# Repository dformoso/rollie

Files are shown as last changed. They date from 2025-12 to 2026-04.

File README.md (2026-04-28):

# Rollie

 

A gravity-stabilised spherical robot — a camera on wheels, where the "wheels" are a hollow 120mm ball and the camera floats at the centre of gravity. It rolls by shifting its own internal mass: pitch the internal weighted platform forward and the ball follows.

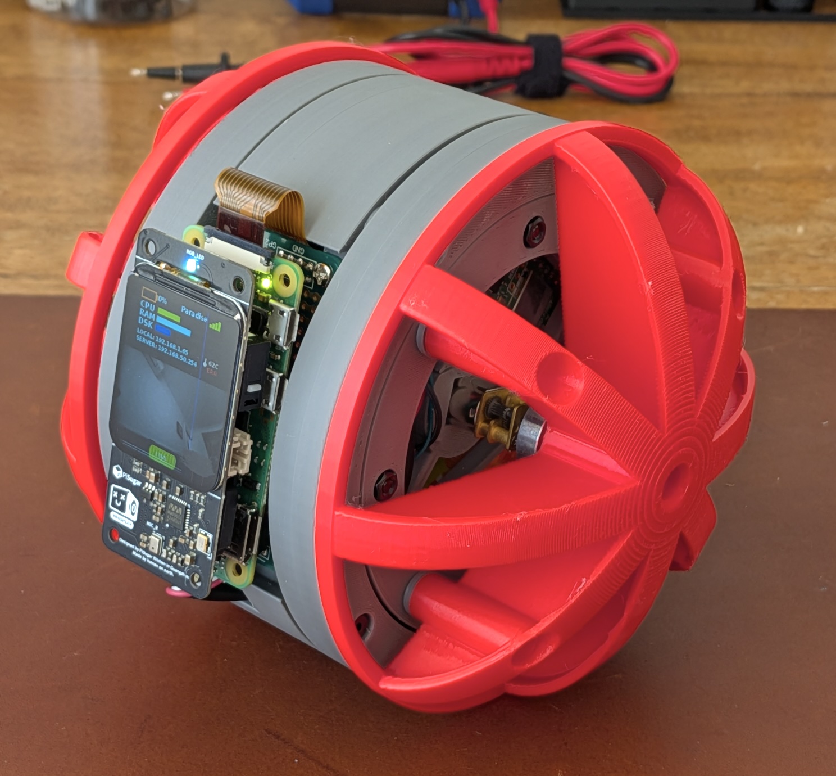
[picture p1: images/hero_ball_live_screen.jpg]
Assembled Rollie — red 3D-printed shells closed around the internal stator, WhisPlay screen showing the live camera feed
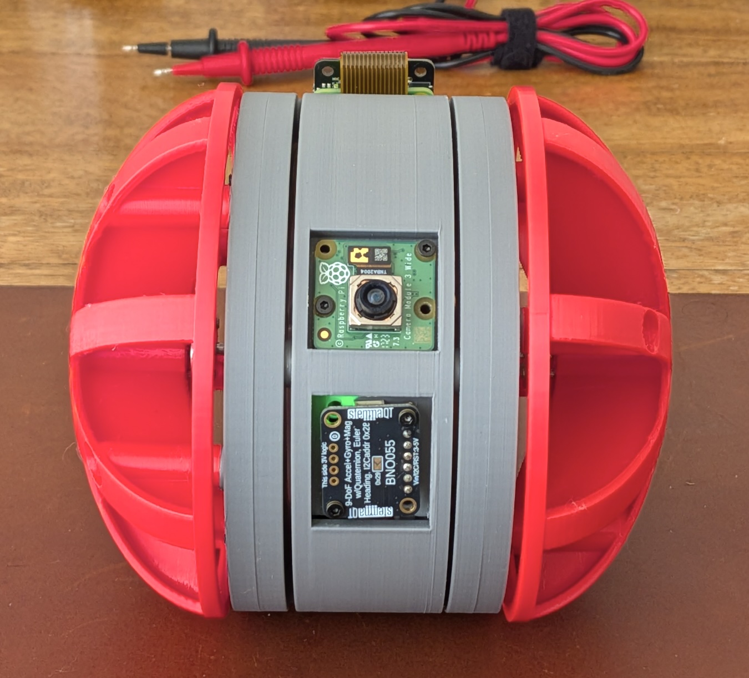
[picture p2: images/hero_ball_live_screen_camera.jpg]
Front view through the equatorial gap — Camera Module 3 Wide and BNO055 IMU exposed between the two red shell halves
&nbsp;&nbsp;

---

## Motivation

This project began with a simple wish: to have more photos and videos together with my son.

I came across [Samsung's concept robot Ballie](https://www.youtube.com/watch?v=v0XdLGYaNMw) — a cheerful, rolling ball that follows you around — and thought: *what if I built one myself?* A little companion that could chase us around the house and capture the everyday moments that are so easy to miss.

The project felt like the right kind of ambitious. Complex enough to keep me engaged for years, but tangible enough to make real progress in the hour I carve out each evening after he goes to sleep.

---

## The Experiment: AI as Co-Engineer

This project started as a question: *how far can AI assistance extend beyond software development?*

The code is the least interesting part. Every engineering layer was designed in collaboration with AI models:

- **Mechanical design** — the slewing bearing rings, stator frame, cradle, and motor hubs were designed iteratively in OpenSCAD with AI help: from geometry constraints and print tolerance adjustments to resolving mechanical interference across 13+ versions of each part.

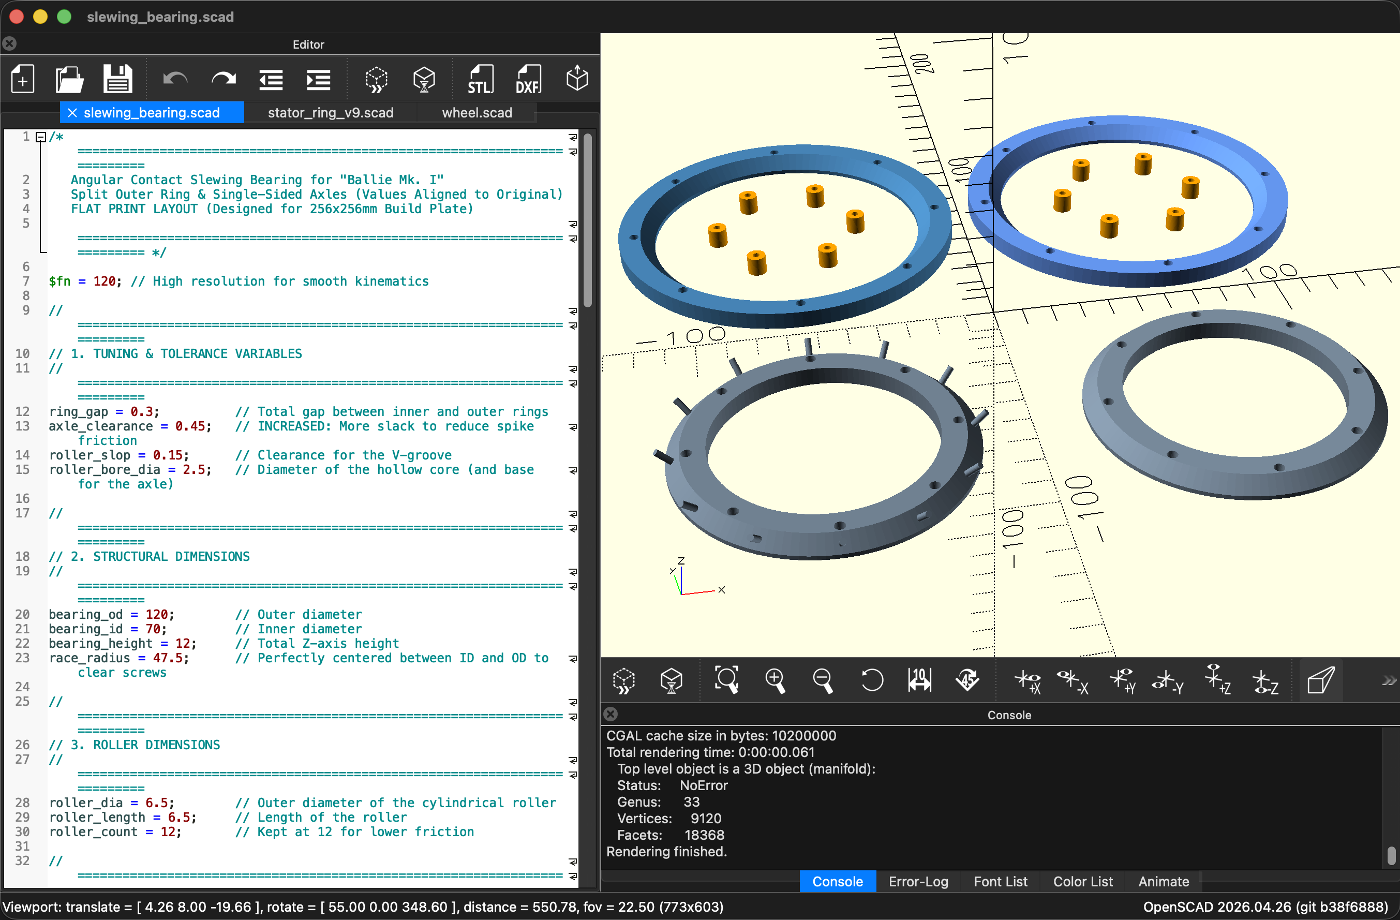
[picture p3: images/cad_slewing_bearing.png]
OpenSCAD source on the left, rendered slewing bearing rings on the right
  

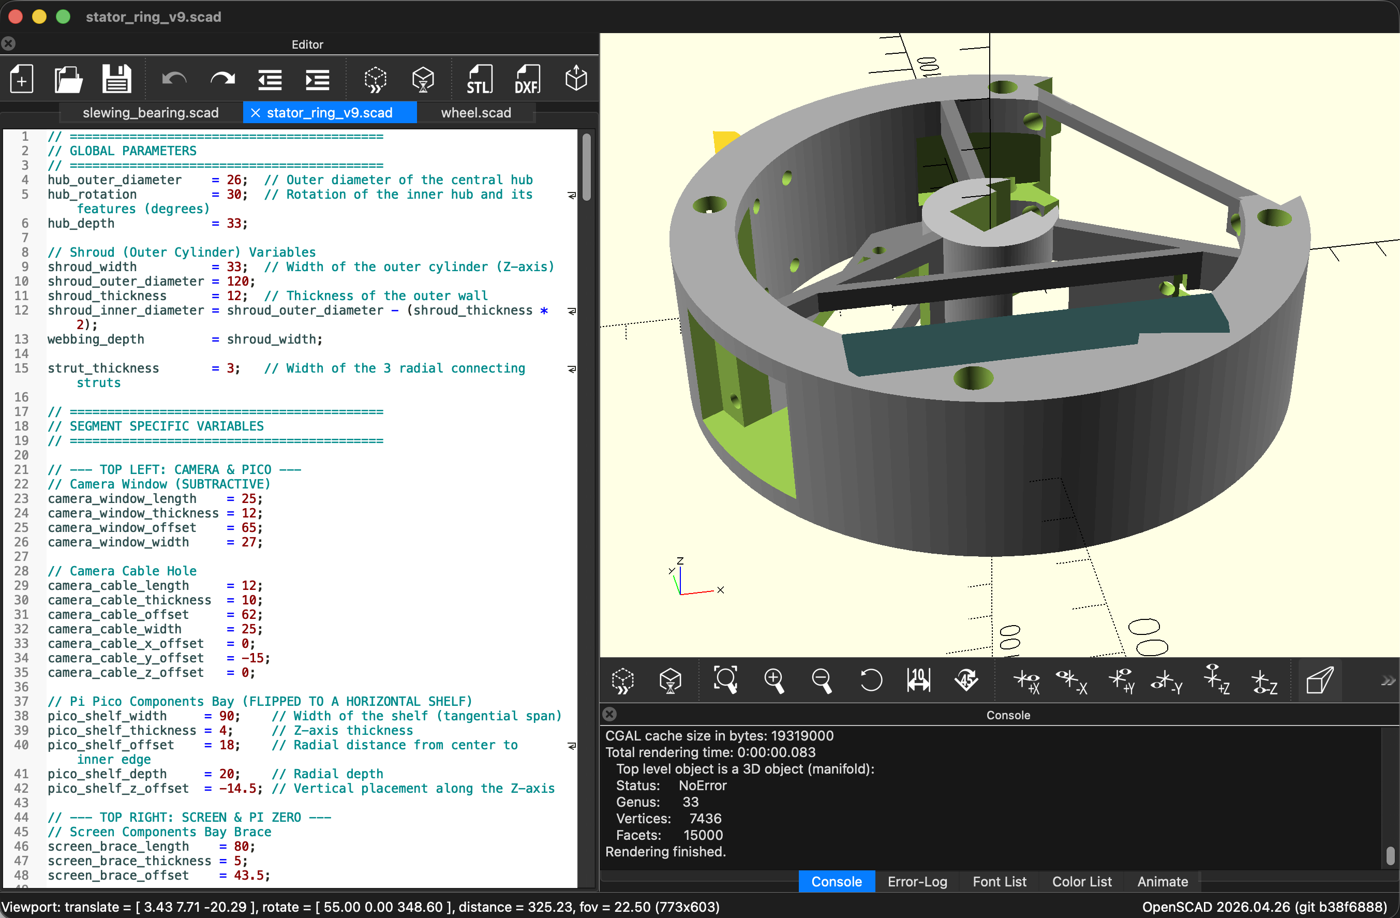
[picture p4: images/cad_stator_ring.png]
OpenSCAD source on the left, rendered stator ring on the right
  

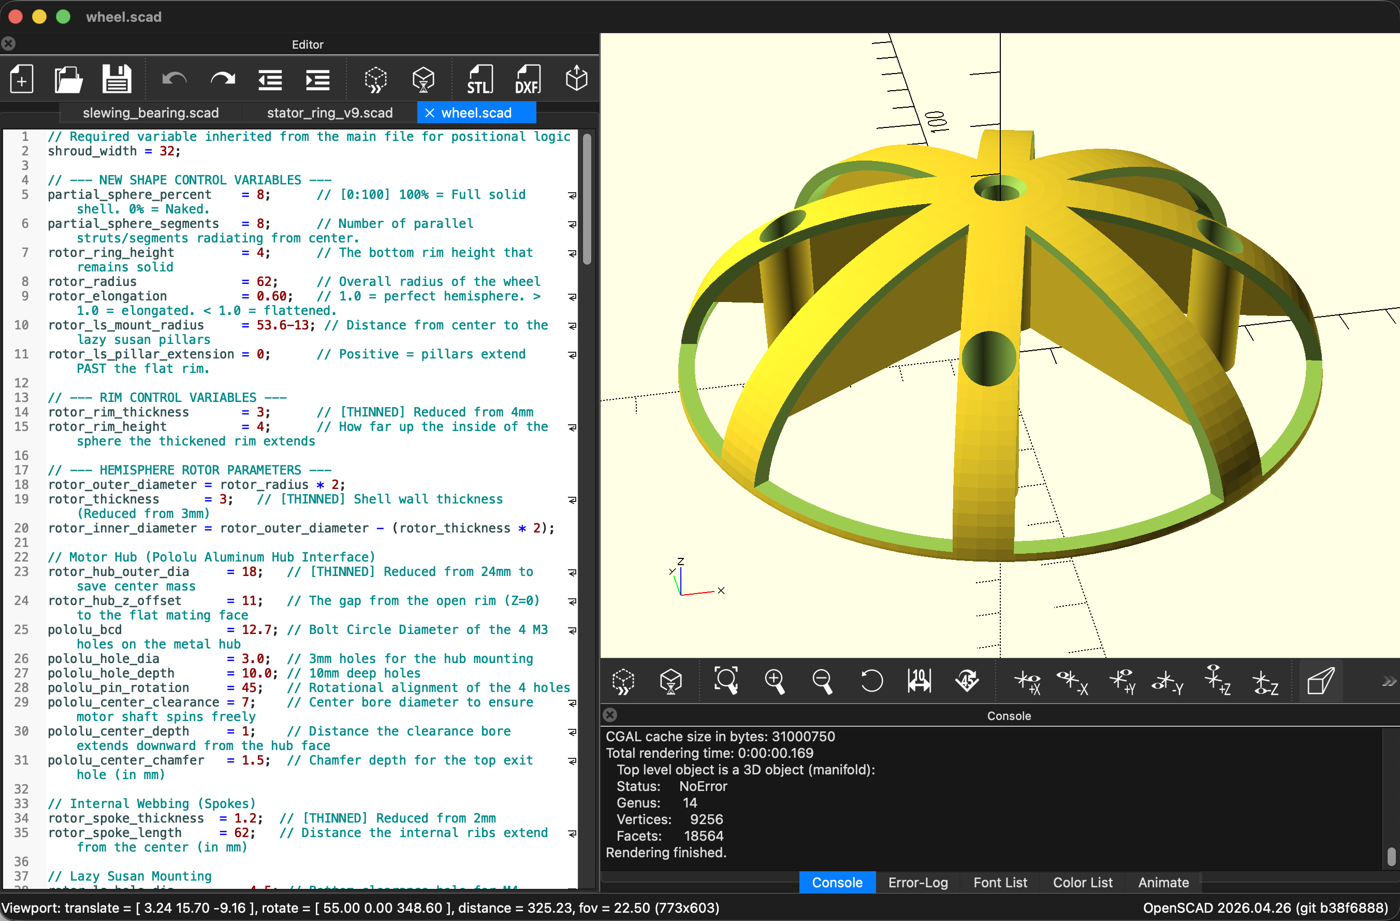
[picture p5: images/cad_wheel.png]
OpenSCAD source on the left, rendered motor wheel hub on the right
  

- **Bill of materials** — the parts list itself (motors, regulator, IMU, bearings, battery, displays) was researched and assembled with AI assistance.

- **Electronic engineering** — wiring layout, component selection, pin assignment (including resolving conflicts between the Motor SHIM's DRV8833, I2C bus, and UART0), and power budgeting were all mapped with AI assistance from a YAML connection list rendered into a wiring diagram.

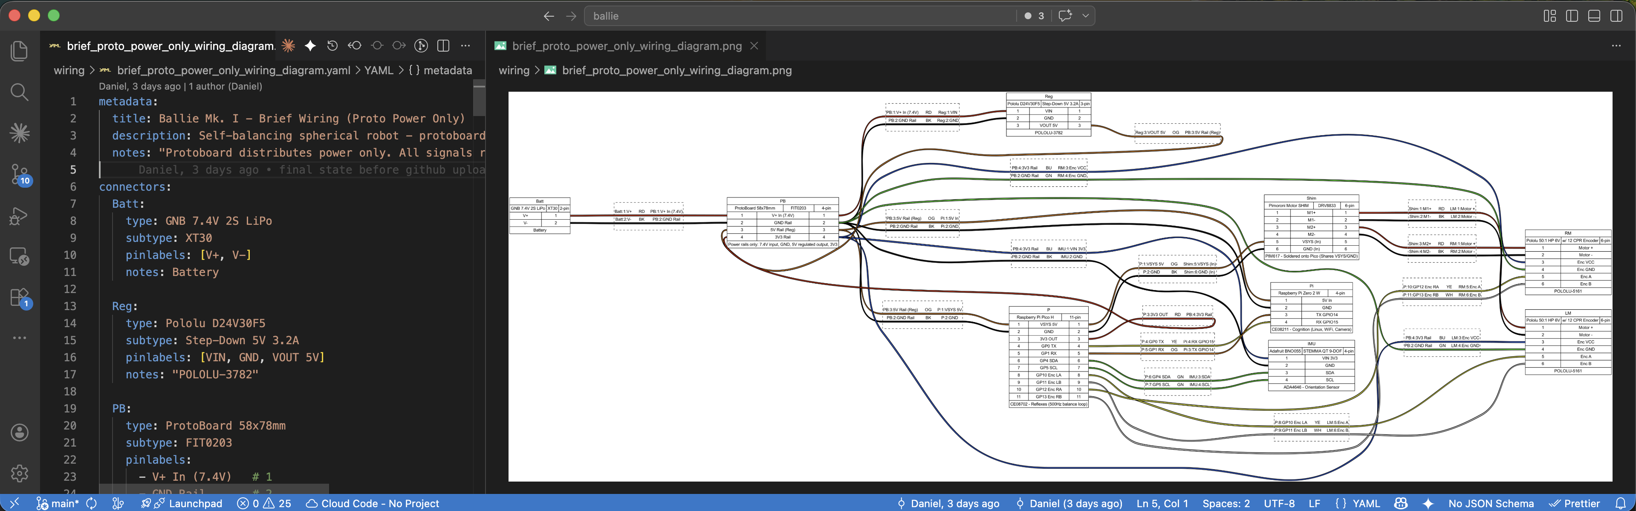
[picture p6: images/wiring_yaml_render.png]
Wiring YAML source open in an editor next to its rendered wiring diagram
  

- **Embedded control** — the split-brain architecture, PID angle controller structure, and motor deadband calibration were designed and reasoned through with AI.

The robot is a physical artefact of that process. It exists to answer the question concretely.

**What AI is not doing (yet):** the models are not steering the robot. Autonomous navigation and perception are a future goal, likely with a small onboard model (Gemma-class). For now, Rollie is remote-controlled.

---

## How It Works

### The Drive Mechanism

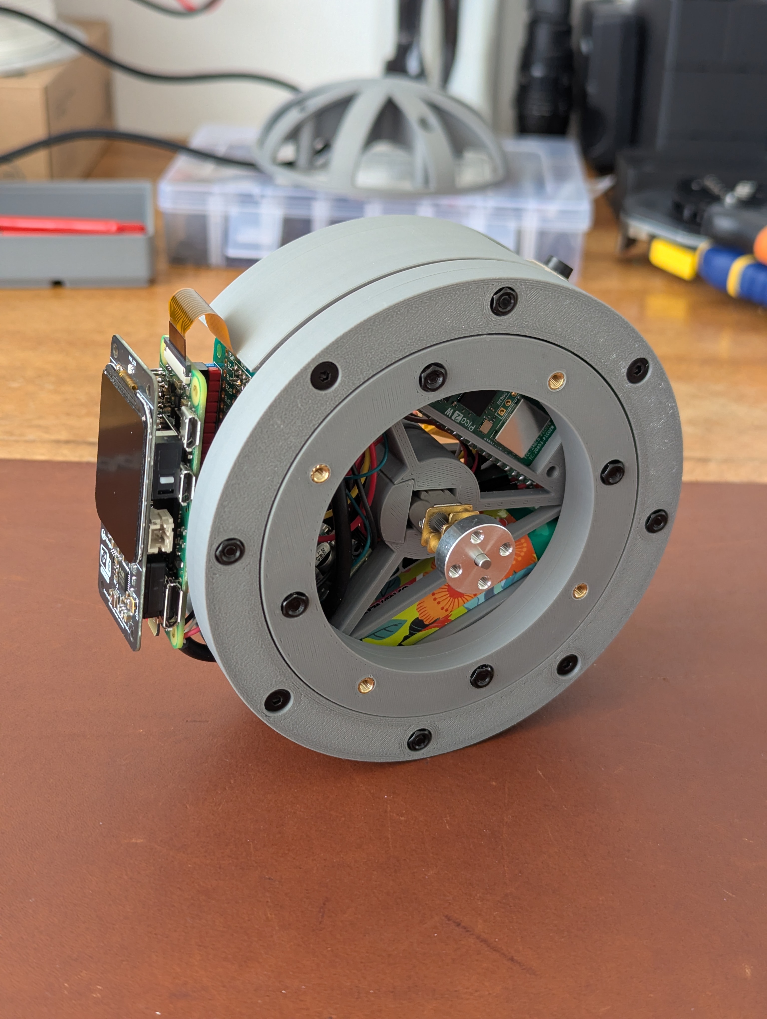
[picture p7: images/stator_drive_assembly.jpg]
Stator drive assembly — both 75mm slewing bearings mounted, motor hub centred, electronics nested inside, before the outer shells go on


Inside the ball is a weighted internal platform — the *stator* — that hangs like a pendulum. Gravity pulls its battery-laden base downward, keeping it vertical. Two motors mounted on the stator drive the outer shell (the *rotor*) through 75mm slewing bearings. Because the stator resists rotation (gravity), the motor reaction force rolls the shell.

To roll forward: command the stator to pitch forward. The centre of mass shifts. The ball follows.

### Architecture: The Split Brain

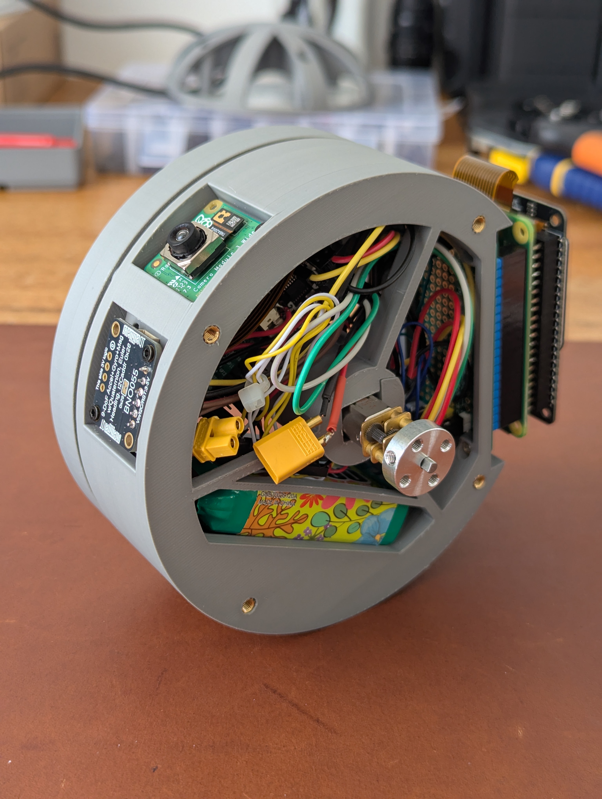
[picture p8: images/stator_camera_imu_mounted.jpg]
Stator with the BNO055 IMU and Camera Module 3 mounted on the top shelf, with the Pi Zero stack visible inside


| Layer | Hardware | Role |
|---|---|---|
| Reflexes | Raspberry Pi Pico 2 W | 100 Hz PID angle control, IMU reading, raw motor PWM |
| Cognition | Raspberry Pi Zero 2 W | Camera streaming, high-level commands, future AI |
| Sensor | Adafruit BNO055 IMU | Absolute orientation via fused Euler angles |
| Driver | Pimoroni Motor SHIM | DRV8833 dual H-bridge for two gear motors |
| Display | WhisPlay (PiSugar 3 HAT) | Live camera feed + system HUD on a 240×280 LCD |

The Pico acts as an *angle-holding coprocessor*. It receives target pitch and yaw angles over UART and runs a PID loop to hold the stator at that angle — which causes the ball to move at the corresponding speed. The Pi Zero (or a dev machine via USB) sends commands:

```
<PITCH:12>   → hold stator at 12° forward tilt (ball rolls forward)
<YAW:5>      → apply differential steering offset
<STOP>       → emergency stop, target = 0°
```

---

## Hardware

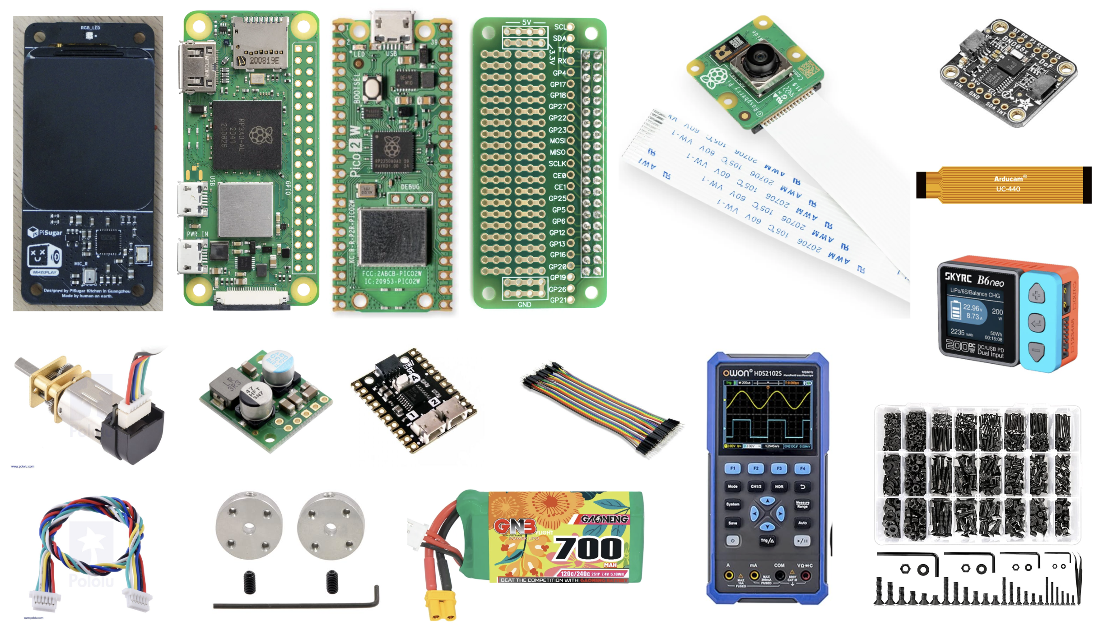
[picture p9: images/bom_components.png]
Component lineup — Pi Zero 2 W, Pico 2 W, Motor SHIM, Camera Module 3, BNO055 IMU, micro metal gearmotors, 5V regulator, 2S LiPo, jumpers, and the test gear that lived next to the bench


Full parts list, pin maps, and wiring tables: [docs/overview.md](docs/overview.md)

**Core components:**

| Qty | Component |
|---|---|
| 1 | Raspberry Pi Zero 2 W |
| 1 | Raspberry Pi Pico 2 W |
| 1 | Adafruit BNO055 9-DOF IMU (STEMMA QT) |
| 1 | Pimoroni Motor SHIM for Pico |
| 2 | Pololu 50:1 Micro Metal Gearmotor HP 6V (extended shaft + encoder) |
| 1 | Pololu 5V 3.2A Step-Down Regulator (D24V30F5) |
| 2 | 75mm Slewing Bearings |
| 1 | GNB 7.4V 2S LiPo (XT30) |
| 1 | PiSugar 3 Battery HAT |
| 1 | Raspberry Pi Camera Module 3 Wide |

---

## Build Guide

### 3D Printing

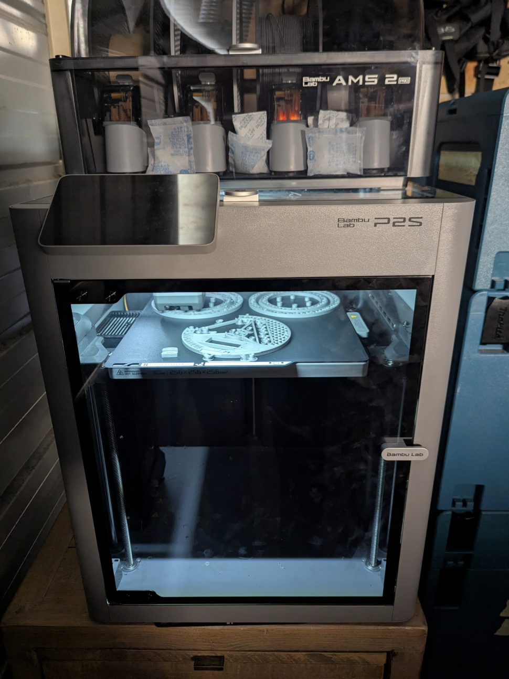
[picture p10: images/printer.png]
Bambu P2S printer with AMS, mid-print on a tray of stator parts


Print the following final STLs from [`cad/`](cad/):

| File | Part | Notes |
|---|---|---|
| `stator_ring_v13.stl` | Internal weighted cylinder | Main structural part |
| `wheel_v13.stl` | Motor wheel hubs | Print ×2 |
| `slewing_bearing_v6_half_plate.stl` | Slewing bearing ring (rigid) | Print ×2 per bearing |
| `slewing_bearing_flexible.stl` | Slewing bearing ring (TPU) | Alternative for grip |
| `cradle_v2.stl` | Electronics mounting cradle | Holds Pi + battery |

SCAD source files for all parts are in `cad/`. Intermediate design iterations are preserved in [`cad/archive/`](cad/archive/).

### Assembly and Wiring
See [docs/overview.md](docs/overview.md) for:

- Full GPIO pin map (Motor SHIM, BNO055, UART, encoders)
- Step-by-step wiring tables with wire colours
- Assembly notes (SHIM sandwich, keel weight placement, cable routing)

---

## Software Setup

### Pico Firmware (MicroPython)

The Pico runs [Pimoroni MicroPython](https://github.com/pimoroni/pimoroni-pico) (v1.27.0+). Flash the UF2 via `sync_and_run_on_py.sh` (see below) or manually.

Deploy firmware files to the Pico:

```bash
python3 pico-shim-firmware/deploy_to_pico.py pico-shim-firmware/
```

The three firmware files are:
- `pico-shim-firmware/main.py` — PID angle controller (main loop)
- `pico-shim-firmware/boot.py` — UART init and boot banner
- `pico-shim-firmware/bno055_minimal.py` — BNO055 I2C driver stub (see note below)

> **BNO055 note:** In v0.1 the IMU driver is a stub. The Pico runs in *Direct Drive* mode, where `<PITCH:x>` maps directly to motor speed rather than a closed-loop angle. A full I2C driver is the next integration step.

### Pi Zero Setup

```bash
cd rollie/
cp config.py.example config.py       # fill in your values
bash install_dependencies.sh
```

---

## Usage

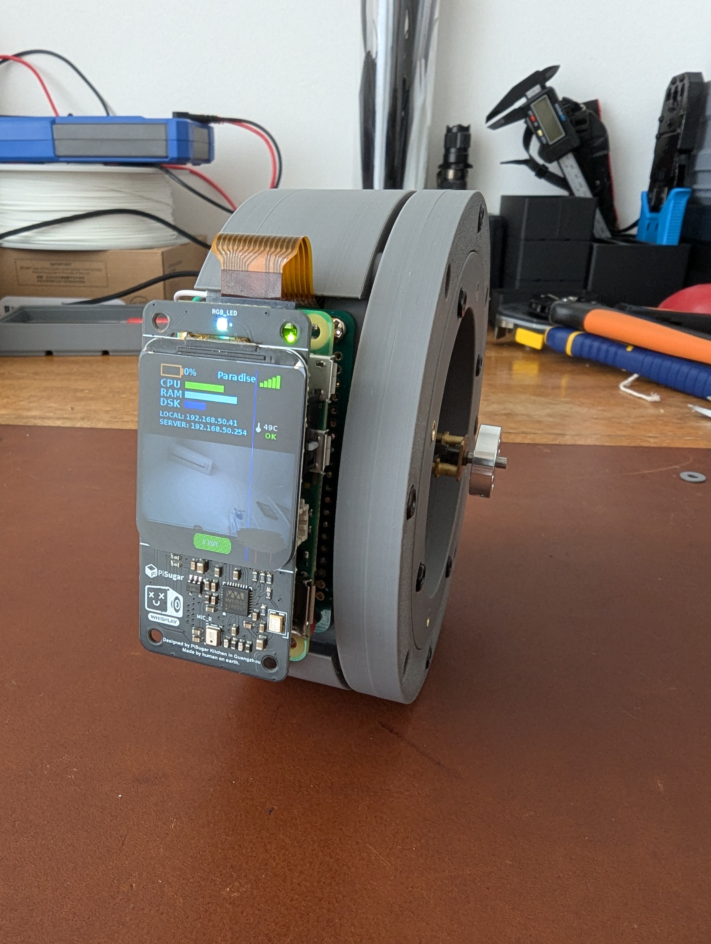
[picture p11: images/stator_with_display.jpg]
WhisPlay display showing the system HUD — CPU, RAM, disk, WiFi, IP addresses, and CPU temperature — on the side of the partially-built stator


### Keyboard Control (dev machine via USB)

Connect the Pico via USB, then:

```bash
python3 pico-shim-firmware/keyboard_control.py
```

| Key | Action |
|---|---|
| W / ↑ | Pitch forward (roll forward) |
| S / ↓ | Pitch backward |
| A / ← | Yaw left |
| D / → | Yaw right |
| Space | Stop |
| +/- | Adjust pitch step size |
| R | Request status |
| Q | Quit |

### Full Deploy to Pi Zero

```bash
cd rollie/
cp sync_config.sh.example sync_config.sh   # fill in Pi IP and credentials
bash sync_and_run_on_py.sh                 # sync + run in foreground
bash sync_and_run_on_py.sh background on   # install as a systemd service
```

---

## Current State — v0.1

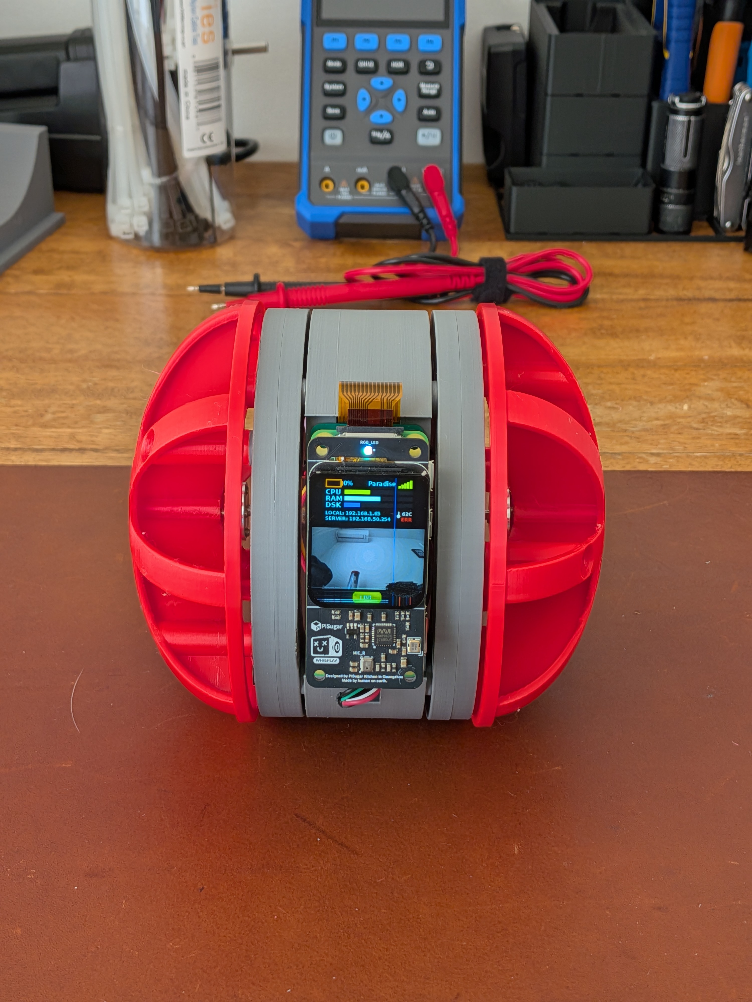
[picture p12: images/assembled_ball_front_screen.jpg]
Assembled Rollie, front-on, screen showing the live camera feed through the equatorial gap
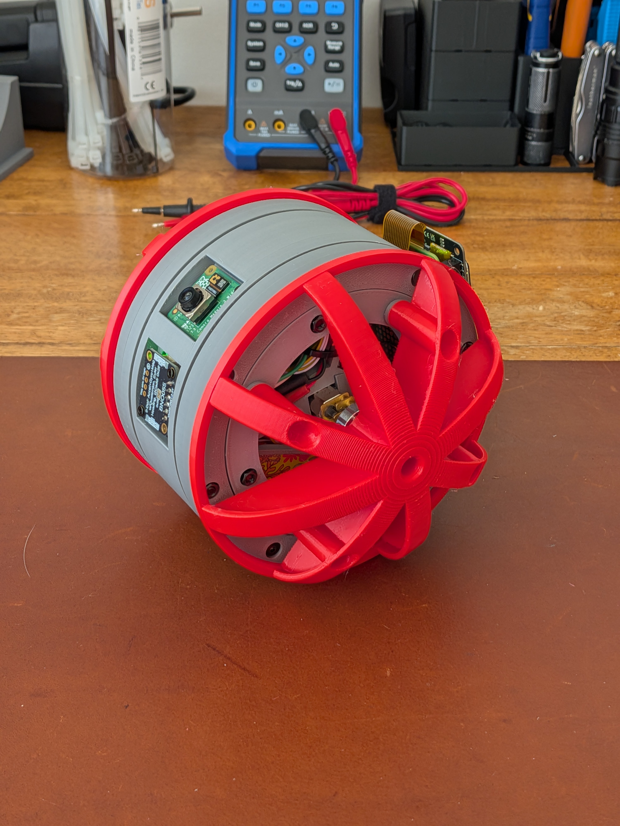
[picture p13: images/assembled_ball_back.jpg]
Assembled Rollie, side/back view, shells closed
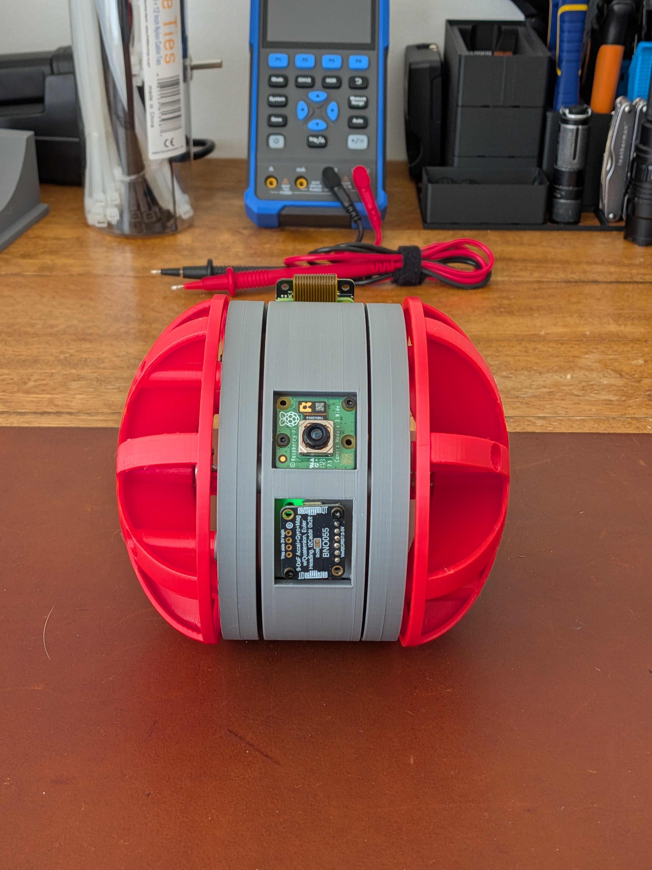
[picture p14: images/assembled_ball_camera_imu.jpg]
Front view through the equatorial gap — Camera Module 3 and BNO055 IMU exposed between the two red shell halves
&nbsp;&nbsp;&nbsp;&nbsp;

A short clip of it rolling: [`images/ball_rolling.mp4`](images/ball_rolling.mp4).

**Working:**
- Physical drive mechanism — ball rolls from pendulum mass shift
- Motor PID velocity loop with encoder feedback
- Camera feed with live system HUD (battery, CPU, WiFi, temperature) on WhisPlay display
- Short-press button: start/stop video + audio recording (auto-muxed to MP4)
- Long-press button: toggle demo mode (sends `<PITCH:30>` to Pico)
- Keyboard control from dev machine (USB) or Pi Zero (UART)

**Not yet integrated:**
- BNO055 IMU closed-loop angle control (currently Direct Drive — stator angle is not sensed)
- End-to-end Pi Zero → Pico UART path (wired, integration untested)
- Onboard AI inference

---

## Next Iteration

The v0.2 goal is to rebuild the control loop in simulation, removing the hardware barrier entirely:

- **Microcontroller sim** — replace the physical Pico with a simulated ESP32 running in [Wokwi](https://wokwi.com/)
- **Physics sim** — a pendulum-in-sphere model (PyBullet or a lightweight 2D pendulum sim) to replace the physical ball
- **Environment sim** — simulated terrain and synthetic camera input
- **AI inference** — a Gemma-class model receiving camera frames and issuing `<PITCH>` / `<YAW>` commands

This makes the project forkable and runnable without hardware, enables RL-based PID tuning, and is a prerequisite for training end-to-end navigation policies.

---

## License

[MIT](LICENSE) — Daniel Martinez Formoso, 2025

---

*Written with Gemini and Claude.*

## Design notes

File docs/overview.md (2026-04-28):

# Project Description: The "Rollie Mk. I" — Spherical Robot

## 1. Overview

**Objective**
To construct an autonomous spherical robot (approx. 120mm diameter) using a gravity-stabilized internal pendulum ("hamster") drive. The robot rolls by displacing its internal center of mass — pitching the stator forward causes the ball to roll forward.

### Core Architecture (The "Split-Brain")

* **The Reflexes (Cerebellum):** A **Raspberry Pi Pico 2 W** runs a dedicated MicroPython control loop. It reads the **BNO055 IMU** and drives the motors via the **Pimoroni Motor SHIM** to hold a precise pitch angle. It acts as an **Angle-Holding Coprocessor**.
* **The Cognition (Cerebrum):** A **Raspberry Pi Zero 2 W** runs Linux. It handles WiFi, Computer Vision (Pi Camera), AI, and high-level path planning. It sends angle commands (e.g., `<PITCH:12>`) to the Pico via UART.

### The Drive Mechanism (Gravity-Stabilized Pendulum)

1. **Stator (Internal):** A weighted cylinder hangs inside the ball. Gravity pulls its battery-laden bottom (**Keel**) downwards, keeping it vertical.
2. **Rotor (External):** Two hemispherical shells form the "skin," mechanically isolated from the Stator by Lazy Susan bearings.
3. **Action:** Motors bolted to the Stator drive the Rotors. Since the Stator resists rotation (gravity), the force rolls the ball. To roll forward, the Pico pitches the stator forward, shifting the center of mass.

---

## 2. Pico Firmware Architecture (The 5-Step Tethered Checklist)

### Step 1: Sensor Fusion (Zeroing the Pendulum)

The BNO055 IMU provides fused accelerometer + gyroscope data. Inside a rolling sphere, the stator acts like a pendulum susceptible to harmonic swinging (wobbling when stopping).

**Goal:** Fast, clean reading of the stator's absolute pitch relative to gravity. Software filter tuned to ignore high-frequency wheel vibrations while catching low-frequency pendulum swings so the motors can counteract them.

The BNO055 runs its own Cortex-M0 sensor fusion internally — we read Euler angles directly via I2C.

### Step 2: PID "Angle Tracking" Loop

Unlike a standard balancing robot (target = 0°), in Rollie the **target angle dictates speed**.

- **Target 0°** → stationary (camera level)
- **Target 10°** → rolling forward at constant speed
- **Target -10°** → rolling backward

The PID loop must smoothly drive motors to hit the target and lock it there rigidly, preventing the stator from bouncing (e.g., between 5° and 15° when targeting 10°).

### Step 3: Motor Deadband & Shell Traction

Find the exact minimum motor power to overcome rolling resistance of the shell on the floor. If the PID commands a small angle change but motors can't overcome friction, the integral term winds up and eventually jerks the camera violently. Deadband calibration ensures smooth, cinematic panning.

### Step 4: Anti-Tumble Limit

If acceleration is too aggressive or the ball hits an obstacle, the stator can swing 360° inside the shell, tearing wiring. **Hard angle limit:** if pitch exceeds ±45°, the Pico instantly overrides PID and applies reverse torque / dynamic braking.

### Step 5: UART Listener (Pi Zero → Pico)

The Pi Zero sends commands like `<PITCH:12>` via UART. The Pico receives the target, executes the PID loop to hold the stator at exactly 12°, and the ball rolls as a physical result.

**Protocol:**
- `<PITCH:xx>` — set target pitch angle (positive = forward)
- `<YAW:xx>` — differential steering (positive = right)
- `<STOP>` — emergency stop, target = 0°, braking

---

## 3. Hardware Pin Map

### Pimoroni Motor SHIM (Soldered onto Pico)

The SHIM is soldered directly onto the top of the Pico headers as per manual. It uses a DRV8833 dual H-bridge.

| Function | GPIO | Physical Pin | Notes |
|---|---|---|---|
| Motor A IN1 | GP6 | Pin 9 | SHIM internal (do NOT use) |
| Motor A IN2 | GP7 | Pin 10 | SHIM internal (do NOT use) |
| Motor B IN1 | GP27 | Pin 32 | SHIM internal (do NOT use) |
| Motor B IN2 | GP26 | Pin 31 | SHIM internal (do NOT use) |
| I2C SDA (STEMMA QT) | GP4 | Pin 6 | (Unused, moved to GP2 to free up UART0) |
| I2C SCL (STEMMA QT) | GP5 | Pin 7 | (Unused, moved to GP3 to free up UART0) |
| NSLEEP | 3V3_EN | — | Always enabled |

### BNO055 IMU (Moved from SHIM STEMMA QT Connector)

The STEMMA QT cable data lines must be routed to GP2 (SDA) and GP3 (SCL) instead of the SHIM's directly.

| BNO055 Pin | Pico Pin | Function |
|---|---|---|
| VIN | 3V3 | Power |
| GND | GND | Ground |
| SDA | GP2 | I2C Data (Moved from GP4) |
| SCL | GP3 | I2C Clock (Moved from GP5) |

I2C Address: `0x28` (default)

### UART — Brain Link (Pi Zero ↔ Pico)

Wires crossed (TX→RX):

| Pi Zero 2 W | Pin # | Pico | Pin # | Wire Color |
|---|---|---|---|---|
| GPIO 14 (TX) | Pin 8 | GP 1 (RX) | Pin 2 | Yellow |
| GPIO 15 (RX) | Pin 10 | GP 0 (TX) | Pin 1 | Orange |
| GND | Pin 6 | GND | Pin 3 | **Black** |

### Motor Encoders (Pololu 50:1 HP with 12 CPR)

**Motor power wires** (Red + Black) connect to the SHIM's motor output pads (soldered).
**Encoder signal wires** connect to Pico GPIO pins (via Dupont connectors to headers).

**Left Motor (Motor 1 / SHIM Motor A)**

| Signal | Wire Color | Connects To | Pin |
|---|---|---|---|
| Motor (+) | Red (thick) | SHIM Pad 1+ | Soldered |
| Motor (−) | Black (thick) | SHIM Pad 1− | Soldered |
| Encoder VCC | Blue | Pico 3V3(OUT) | Pin 36 |
| Encoder GND | Green | Common GND rail | Protoboard |
| Encoder Ch A | Yellow | Pico **GP18** | Pin 24 |
| Encoder Ch B | White | Pico **GP19** | Pin 25 |

**Right Motor (Motor 2 / SHIM Motor B)**

| Signal | Wire Color | Connects To | Pin |
|---|---|---|---|
| Motor (+) | Red (thick) | SHIM Pad 2+ | Soldered |
| Motor (−) | Black (thick) | SHIM Pad 2− | Soldered |
| Encoder VCC | Blue | Pico 3V3(OUT) | Pin 36 |
| Encoder GND | Green | Common GND rail | Protoboard |
| Encoder Ch A | Yellow | Pico **GP16** | Pin 21 |
| Encoder Ch B | White | Pico **GP17** | Pin 22 |

> **Encoder Pin Warning:** Do NOT move encoders to GP6, 7, 26, or 27. Those are used by the Motor SHIM's DRV8833.

### Encoder Constants

| Parameter | Value |
|---|---|
| Motor gear ratio | 51.45:1 |
| Encoder CPR (motor shaft) | 12 |
| Counts per output revolution | 12 × 51.45 ≈ **617** |

---

## 4. Full Parts Listing

### Electronics Core

| Qty | Component | Product Name | SKU |
|---|---|---|---|
| 1 | Brain | Raspberry Pi Zero 2 W | CE08211 |
| 1 | Reflexes | Raspberry Pi Pico 2 W | — |
| 1 | IMU | Adafruit BNO055 9-DOF (STEMMA QT) | ADA4646 |
| 1 | Regulator | Pololu 5V, 3.2A Step-Down (D24V30F5) | POLOLU-3782 |
| 1 | Motor Driver | Pimoroni Motor SHIM for Pico | PIM617 |
| 1 | Motherboard | ProtoBoard 2" (58×78mm) | FIT0203 |

### Drive System

| Qty | Component | Product Name | SKU |
|---|---|---|---|
| 2 | Motors | Pololu 50:1 Micro Metal Gearmotor HP 6V (Extended Shaft + Encoder) | POLOLU-5161 |
| 2 | Cables | 6-Pin JST SH-Style Cable (16cm) | POLOLU-4766 |
| 2 | Bearings | 75mm Lazy Susan Bearing | — |
| 1 | Battery | GNB 7.4V 2S LiPo (XT30) | — |

---

## 5. Assembly Notes

> **The SHIM Sandwich:** Solder the Pimoroni Motor SHIM onto the Pico's pins **before** plugging the Pico into the motherboard sockets. Text on SHIM and pin labels on Pico back should face each other.

> **BNO055 Connection:** The BNO055 SDA connects to Pico GP2 and SCL to GP3 (moved from the SHIM's default GP4/GP5 to avoid UART conflicts). Power and ground can still be drawn from the SHIM or common rails.

> **Cable Modifications:** The 6-pin Pololu motor cables were severed — thick Red+Black soldered to SHIM motor pads, thin Green/White/Yellow/Blue crimped with Dupont connectors for Pico GPIO headers.

> **The Keel Weight:** Battery must be mounted as low as possible inside the stator ring. The robot will not balance correctly if the battery is high.

> **Cable Slack:** Motor cables must be zip-tied to the Stator frame so they don't rub against the rotating Lazy Susan or outer shells.

---

## 6. Software Stack

| Layer | Runs On | Language | Responsibility |
|---|---|---|---|
| `main.py` | Pico 2 W | MicroPython v1.27.0 | PID angle control, IMU reading, raw PWM motor driving, UART listening |
| `boot.py` | Pico 2 W | MicroPython | UART init, boot banner |
| `bno055_minimal.py` | Pico 2 W | MicroPython | Minimal BNO055 I2C driver |
| `camera_feed.py` | Pi Zero 2 W | Python 3 | Camera streaming, AI, high-level control |
| `sync_and_run_on_py.sh` | Dev Machine | Bash | Deploys firmware to Pico (USB), syncs to Pi Zero |
| `keyboard_control.py` | Dev Machine | Python 3 | Debug tool — sends angle commands via USB serial |

### Communication Flow

```
Dev Machine (keyboard_control.py)
    ↓ USB Serial (/dev/ttyACM0, 9600 baud)
Pico 2 W (main.py — PID angle controller)
    ↕ I2C1 (GP2/GP3)       ↕ PWM (SHIM GP6/7/26/27)
BNO055 IMU                  Motors (via DRV8833)

Future (untethered):
Pi Zero 2 W (camera_feed.py)
    ↓ UART0 (GP0/GP1, 9600 baud)
Pico 2 W (main.py)
```

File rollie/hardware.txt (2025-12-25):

Main Device: Raspberry Pi Zero 2W
HAT1: PiSugar 3 Whisplay
HAT2: PiSugar 3 Battery
Camera: Raspberry Pi Camera Module 3 Wide

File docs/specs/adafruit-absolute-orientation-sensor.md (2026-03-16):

# Adafruit BNO055 Absolute Orientation Sensor

> **Source:** [Adafruit Learning Guide](https://learn.adafruit.com/adafruit-bno055-absolute-orientation-sensor)
> **Last Updated:** 2025-05-16

---

## Overview

If you've ever ordered and wired up a 9-DOF sensor, chances are you've also realized the challenge of turning the sensor data from an accelerometer, gyroscope and magnetometer into actual "3D space orientation"! Orientation is a hard problem to solve. The sensor fusion algorithms (the secret sauce that blends accelerometer, magnetometer and gyroscope data into stable three-axis orientation output) can be mind-numbingly difficult to get right and implement on low cost real time systems.

Bosch is the first company to get this right by taking a MEMS accelerometer, magnetometer and gyroscope and putting them on a single die with a high speed ARM Cortex-M0 based processor to digest all the sensor data, abstract the sensor fusion and real time requirements away, and spit out data you can use in quaternions, Euler angles or vectors.

> **Note:** The BNO055 I2C implementation violates the I2C protocol in some circumstances. This causes it not to work well with certain chip families. It does not work well with NXP i.MX RT1011, and it does not work well with I2C multiplexers. With ESP32 and ESP32-S3, CircuitPython 9.2.2 and later (which use ESP-IDF 5.3.2 and later) work better. Operation with SAMD51, RP2040, STM32F4, and nRF52840 is more reliable.

The board includes SparkFun qwiic compatible STEMMA QT connectors for the I2C bus so you don't even need to solder!

### Data Output

The BNO055 can output the following sensor data:

- **Absolute Orientation (Euler Vector, 100Hz)** — Three axis orientation data based on a 360° sphere
- **Absolute Orientation (Quaternion, 100Hz)** — Four point quaternion output for more accurate data manipulation
- **Angular Velocity Vector (100Hz)** — Three axis of 'rotation speed' in rad/s
- **Acceleration Vector (100Hz)** — Three axis of acceleration (gravity + linear motion) in m/s²
- **Magnetic Field Strength Vector (20Hz)** — Three axis of magnetic field sensing in micro Tesla (uT)
- **Linear Acceleration Vector (100Hz)** — Three axis of linear acceleration data (acceleration minus gravity) in m/s²
- **Gravity Vector (100Hz)** — Three axis of gravitational acceleration (minus any movement) in m/s²
- **Temperature (1Hz)** — Ambient temperature in degrees Celsius

### Related Resources

- [Datasheet](https://adafru.it/f0H)
- [Adafruit BNO055 Library (GitHub)](https://adafru.it/f0I)
- [Comparing the BNO085 vs BNO055 (Adafruit Forums)](https://adafru.it/19Cb)

---

## Pinouts

> **Note:** The pin order on the STEMMA QT version of the board is not the same as the original version. The pins are the same otherwise.

### Power Pins

| Pin | Description |
|-----|---|
| **VIN** | 3.3–5.0V power supply input |
| **3VO** | 3.3V output from the on-board linear voltage regulator, up to ~50mA |
| **GND** | Common/GND pin for power and logic |

### I2C Pins

| Pin | Description |
|-----|---|
| **SCL** | I2C clock pin. Works with 3V or 5V logic. 10K pullup included. |
| **SDA** | I2C data pin. Works with 3V or 5V logic. 10K pullup included. |

### STEMMA QT Version

STEMMA QT connectors allow you to connect to dev boards with STEMMA QT connectors or to other things with various associated accessories.

### Other Pins

| Pin | Description |
|-----|---|
| **RST** | Hardware reset pin. Set low then high to reset. 5V safe. |
| **INT** | HW interrupt output pin (not currently supported in Adafruit library). 3V output. |
| **ADR** | Set high to change the default I2C address if connecting two ICs on the same bus. |
| **PS0 / PS1** | Mode change pins (HID-I2C, UART). Normally left unconnected. |

---

## Assembly

1. **Prepare the header strip:** Cut the strip to length if necessary. Insert into a breadboard — long pins down.
2. **Add the breakout board:** Place the breakout board over the pins so that the short pins poke through the breakout pads.
3. **Solder:** Be sure to solder all pins for reliable electrical contact. Solder the longer power/data strip first.

---

## Arduino Code

### Wiring for Arduino

Connect the assembled BNO055 breakout to an Arduino Uno:

- **Vin** (red wire) → power supply (3–5V)
- **GND** (black wire) → common ground
- **SCL** (blue wire) → I2C clock (A5 on Uno, digital 21 on Mega, digital 3 on Leonardo)
- **SDA** (yellow wire) → I2C data (A4 on Uno, digital 20 on Mega, digital 2 on Leonardo)

> **Note:** If using a Genuino Zero or Arduino Zero with the built-in EDBG interface, you may need to use I2C address `0x29` since `0x28` is 'taken' by the DBG chip.

### Software

Install via the Arduino Library Manager:

1. Search for and install the **Adafruit Sensor** library
2. Search for and install the **Adafruit BNO055** library

### Adafruit Unified Sensor System

```cpp
#include <Wire.h>
#include <Adafruit_Sensor.h>
#include <Adafruit_BNO055.h>
#include <utility/imumaths.h>

Adafruit_BNO055 bno = Adafruit_BNO055(55);

void setup(void) {
    Serial.begin(9600);
    Serial.println("Orientation Sensor Test");

    if (!bno.begin()) {
        Serial.print("Ooops, no BNO055 detected ... Check your wiring or I2C ADDR!");
        while (1);
    }

    delay(1000);
    bno.setExtCrystalUse(true);
}

void loop(void) {
    sensors_event_t event;
    bno.getEvent(&event);

    Serial.print("X: "); Serial.print(event.orientation.x, 4);
    Serial.print("\tY: "); Serial.print(event.orientation.y, 4);
    Serial.print("\tZ: "); Serial.print(event.orientation.z, 4);
    Serial.println("");

    delay(100);
}
```

### Raw Sensor Data

Key raw data functions:

- **`.getVector(adafruit_vector_type_t vector_type)`** — Returns 3-axis vector data
  - `VECTOR_MAGNETOMETER` (uT)
  - `VECTOR_GYROSCOPE` (rad/s)
  - `VECTOR_EULER` (degrees, 0–359)
  - `VECTOR_ACCELEROMETER` (m/s²)
  - `VECTOR_LINEARACCEL` (m/s²)
  - `VECTOR_GRAVITY` (m/s²)

- **`.getQuat(void)`** — Returns a Quaternion (easier and more accurate than Euler angles)

- **`.getTemp(void)`** — Returns ambient temperature in °C

---

## Device Calibration

The BNO055 includes internal algorithms to constantly calibrate the gyroscope, accelerometer and magnetometer inside the device.

Four calibration registers return a value between `0` (uncalibrated) and `3` (fully calibrated).

> **Important:** When running in NDOF mode, any data where the system calibration value is `0` should generally be ignored.

### Generating Calibration Data

- **Gyroscope:** The device must be standing still in any position
- **Magnetometer:** Perform figure-8 motions (with recent devices, fast magnetic compensation takes place with normal movement)
- **Accelerometer:** Place in 6 standing positions for +X, -X, +Y, -Y, +Z and -Z

### Persisting Calibration Data

The BNO doesn't contain any internal EEPROM. You will need to perform a new calibration every time the device starts up, or manually restore previous calibration values.

---

## Python & CircuitPython

### I2C Initialization

```python
import board
import busio
import adafruit_bno055

i2c = busio.I2C(board.SCL, board.SDA)
sensor = adafruit_bno055.BNO055_I2C(i2c)
```

### UART Initialization (CircuitPython)

```python
import board
import busio
import adafruit_bno055

uart = busio.UART(board.TX, board.RX)
sensor = adafruit_bno055.BNO055_UART(uart)
```

### UART Initialization (Python / Raspberry Pi)

```python
import serial
import adafruit_bno055

uart = serial.Serial("/dev/serial0")
sensor = adafruit_bno055.BNO055_UART(uart)
```

### Available Properties

| Property | Description |
|---|---|
| `temperature` | Sensor temperature in °C |
| `acceleration` | (X, Y, Z) accelerometer values in m/s² |
| `magnetic` | (X, Y, Z) magnetometer values in microteslas |
| `gyro` | (X, Y, Z) gyroscope values in degrees/sec |
| `euler` | (heading, roll, pitch) orientation Euler angles |
| `quaternion` | (w, x, y, z) orientation quaternion values |
| `linear_acceleration` | (X, Y, Z) linear acceleration (no gravity) in m/s² |
| `gravity` | (X, Y, Z) gravity acceleration (no linear) in m/s² |

### Full Example Code

```python
import time
import board
import adafruit_bno055

i2c = board.I2C()
sensor = adafruit_bno055.BNO055_I2C(i2c)

last_val = 0xFFFF

def temperature():
    global last_val
    result = sensor.temperature
    if abs(result - last_val) == 128:
        result = sensor.temperature
        if abs(result - last_val) == 128:
            return 0b00111111 & result
    last_val = result
    return result

while True:
    print(f"Temperature: {sensor.temperature} degrees C")
    print(f"Accelerometer (m/s^2): {sensor.acceleration}")
    print(f"Magnetometer (microteslas): {sensor.magnetic}")
    print(f"Gyroscope (rad/sec): {sensor.gyro}")
    print(f"Euler angle: {sensor.euler}")
    print(f"Quaternion: {sensor.quaternion}")
    print(f"Linear acceleration (m/s^2): {sensor.linear_acceleration}")
    print(f"Gravity (m/s^2): {sensor.gravity}")
    print()
    time.sleep(1)
```

### Python Installation

```bash
sudo pip3 install adafruit-circuitpython-bno055
```

> **Note:** Older versions of the Raspberry Pi firmware do not have I2C clock stretching support. Please ensure your firmware is updated and slow down the I2C as explained [here](https://learn.adafruit.com/circuitpython-on-raspberrypi-linux/i2c-clock-stretching).

---

## BNO055 Sensor Calibration in CircuitPython

### Stand-alone Calibrator

```python
import time
import board
import adafruit_bno055

class Mode:
    CONFIG_MODE = 0x00
    NDOF_MODE = 0x0C

i2c = board.STEMMA_I2C()
sensor = adafruit_bno055.BNO055_I2C(i2c)
sensor.mode = Mode.NDOF_MODE

# Step 1: Magnetometer - figure-eight dance
print("Magnetometer: Perform the figure-eight calibration dance.")
while not sensor.calibration_status[3] == 3:
    print(f"Mag Calib Status: {100 / 3 * sensor.calibration_status[3]:3.0f}%")
    time.sleep(1)
print("... CALIBRATED")

# Step 2: Accelerometer - six-step rotate
print("Accelerometer: Perform the six-step calibration dance.")
while not sensor.calibration_status[2] == 3:
    print(f"Accel Calib Status: {100 / 3 * sensor.calibration_status[2]:3.0f}%")
    time.sleep(1)
print("... CALIBRATED")

# Step 3: Gyroscope - hold still
print("Gyroscope: Perform the hold-in-place calibration dance.")
while not sensor.calibration_status[1] == 3:
    print(f"Gyro Calib Status: {100 / 3 * sensor.calibration_status[1]:3.0f}%")
    time.sleep(1)
print("... CALIBRATED")

print("\nCALIBRATION COMPLETED")
print(f"  Offsets_Magnetometer:  {sensor.offsets_magnetometer}")
print(f"  Offsets_Gyroscope:     {sensor.offsets_gyroscope}")
print(f"  Offsets_Accelerometer: {sensor.offsets_accelerometer}")
```

### User Orientation Offset (Target Angle Offset)

A user orientation offset to correct for the alignment of the display in relationship with the sensor. Changing the target angle offset doesn't recalibrate the sensor — it just uses the current Euler angle to provide the offset for future position readings.

### Tap Detection

The BNO055 does not have native tap detection. A simple non-blocking single and double tap detection scheme can use the accelerometer's 100Hz data rate as a high-pass filter by measuring the delta between two consecutive measurements.

- **Tap sensitivity threshold:** 1.0 (overly sensitive) → 5.0 (typical) → 10.0 (numb)
- **Tap debounce:** 0.1s (securely mounted) → 0.3s (typical) → 0.5s (loosely mounted)

---

## FAQs

**Q: Can I manually set the calibration constants?**
Yes — save and restore calibration using the `restore_offsets` example. Note that the magnetometer needs recalibration even if offsets are loaded, as EMF environment changes.

**Q: Does the device make any assumptions about its initial orientation?**
Axes can be customized (see section 3.4 of the BNO055 datasheet). Until calibrated, orientation output is relative to power-on position.

**Q: Why doesn't Euler output seem to match the Quaternion output?**
Euler angles from the chip are based on "automatic orientation detection" and should only be used for eCompass where pitch and roll stay below 45°. For absolute orientation, always use quaternions.

**Q: I'm getting I2C errors in CircuitPython?**
The BNO055 I2C implementation violates the protocol in some cases. Works best with SAMD51, RP2040, STM32F4, and nRF52840.

**Q: I'm losing data over I2C?**
Add stronger pullups — 3.3K on SCL and 2.2K on SDA to override the default 10K pullups.

---

## Downloads

- [Arduino Library (GitHub)](https://adafru.it/f0I)
- [EagleCAD PCB files (GitHub)](https://adafru.it/sEn)
- [BNO055 STEMMA 3D models (GitHub)](https://adafru.it/11Am)
- [BNO055 Datasheet (2021)](https://adafru.it/19Cj)
- [Fritzing object (Adafruit Fritzing Library)](https://adafru.it/aP3)

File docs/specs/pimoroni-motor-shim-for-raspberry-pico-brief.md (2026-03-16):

# Motor SHIM for Pico — Product Brief

> **Manufacturer:** [Pimoroni](https://shop.pimoroni.com/products/motor-shim-for-pico)

---

## Overview

Motor SHIM for Pico is a neat little add-on board that lets you drive two micro metal gearmotors from a Raspberry Pi Pico — tiny robots ahoy!

Solder this SHIM to the back of your Pico and unlock the ability to plug in up to two micro metal gearmotors using [short motor cables](https://shop.pimoroni.com/products/motor-shim-cable). To connect them via cable, your motors will need to be equipped with [Motor Connector Shims](https://shop.pimoroni.com/products/motor-connector-shim) (also available [with motors pre-attached](https://shop.pimoroni.com/products/micro-metal-gearmotor-with-motor-connector-shim)).

In addition to the motor driver, Motor SHIM for Pico features a multi-purpose user button plus a Qw/ST connector so you can attach breakouts and give your robot some smarts.

Motor SHIM is designed to be as slimline as possible and uses minimal pins so it can be combined easily with other add-ons like [Pico Packs and Bases](https://shop.pimoroni.com/collections/pico).

## Key Features

- **Dual H-Bridge motor driver** (DRV8833)
- 2× JST-ZH connectors (2 pin) for attaching motors
- User button
- Qw/ST (Qwiic/STEMMA QT) connector for attaching breakouts
- Compatible with Raspberry Pi Pico
- Soldering required

## Dimensions

Approx **26mm × 21mm × 5mm** (L × W × H, including connectors)

## Assembly

Solder the SHIM to the back of your Pico, with the mounting holes lining up at the USB port end. The `PICO MOTOR SHIM` text on the SHIM and the pin labels on the back of the Pico should be facing each other.

## Software

### MicroPython

- [Download Pirate brand MicroPython](https://github.com/pimoroni/pimoroni-pico/releases)
- [MicroPython API documentation](https://github.com/pimoroni/pimoroni-pico/tree/main/micropython/modules/motor)
- [MicroPython examples](https://github.com/pimoroni/pimoroni-pico/tree/main/micropython/examples/pico_motor_shim)

### C++

- [C++ examples](https://github.com/pimoroni/pimoroni-pico/tree/main/examples/pico_motor_shim)

### CircuitPython

- [Getting Started with CircuitPython](https://learn.adafruit.com/welcome-to-circuitpython)
- [CircuitPython example](https://github.com/pimoroni/pico-circuitpython-examples/tree/main/pico_motor_shim)

## Resources

- [C++/MicroPython libraries (GitHub)](https://github.com/pimoroni/pimoroni-pico)
- [Schematic (PDF)](https://cdn.shopify.com/s/files/1/0174/1800/files/motor_shim_schematic.pdf?v=1652702111)

## Notes

- If you'd prefer not to attach Motor SHIM permanently to your Pico, consider soldering it to a pair of socket headers.
- For battery-powered robots, consider combining with a [LiPo SHIM for Pico](https://shop.pimoroni.com/products/pico-lipo-shim) or using a [Pimoroni Pico LiPo](https://shop.pimoroni.com/products/pimoroni-pico-lipo).
- Raspberry Pi Pico, headers and other components are sold separately.

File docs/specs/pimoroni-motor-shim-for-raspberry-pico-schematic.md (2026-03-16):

# Motor SHIM for Pico — Schematic

> **Source:** [Pimoroni Motor SHIM Schematic (PDF)](https://cdn.shopify.com/s/files/1/0174/1800/files/motor_shim_schematic.pdf?v=1652702111)

---

## Motor Driver IC

**DRV8833PWP** — Dual H-Bridge Motor Driver

## Pi Pico Pin Mapping

| Pico Pin | Function | Description |
|---|---|---|
| GP6 | MOT_AP | Motor A, Input 1 (AIN1) |
| GP7 | MOT_AN | Motor A, Input 2 (AIN2) |
| GP27 (ADC1) | MOT_BP | Motor B, Input 1 (BIN1) |
| GP26 (ADC0) | MOT_BN | Motor B, Input 2 (BIN2) |
| GP4 | SDA | I2C Data (Qw/ST connector) |
| GP5 | SCL | I2C Clock (Qw/ST connector) |
| 3V3_EN | NSLEEP | DRV8833 sleep control (active low) |

## DRV8833 Connections

```
                 DRV8833PWP
           ┌────────────────────┐
    VM ────┤ VM         AIN1   ├──── MOT_AP (GP6)
           │            AIN2   ├──── MOT_AN (GP7)
    VCP ───┤ VCP        BIN1   ├──── MOT_BP (GP27)
           │            BIN2   ├──── MOT_BN (GP26)
    VINT ──┤ VINT              │
           │           AOUT1   ├──── OUT_MOT_AP ─── Motor A (+)
 3V3_EN ──┤ NSLEEP    AOUT2   ├──── OUT_MOT_AN ─── Motor A (-)
           │           BOUT1   ├──── OUT_MOT_BP ─── Motor B (+)
           │  NFAULT   BOUT2   ├──── OUT_MOT_BN ─── Motor B (-)
           │                   │
           │  AISEN            │
           │  BISEN            │
    GND ───┤ GND               │
           └────────────────────┘
```

## Current Sensing Resistors

- **R13, R14:** 0.82Ω each
- **Current limit formula:** `Current = 200mV / Resistance`
- With 0.82Ω: **0.244A** current limit per motor channel
- **Resistor power dissipation:** 0.244A × 0.2V = **0.049W**

## Motor Connectors

Two JST-ZH 2-pin connectors:

| Connector | Pin 1 | Pin 2 |
|---|---|---|
| Motor A | OUT_MOT_AP | OUT_MOT_AN |
| Motor B | OUT_MOT_BP | OUT_MOT_BN |

## Qw/ST (I2C) Connector

| Pin | Signal |
|-----|---|
| 1 | — |
| 2 | — |
| 3 | SDA (GP4) |
| 4 | SCL (GP5) |

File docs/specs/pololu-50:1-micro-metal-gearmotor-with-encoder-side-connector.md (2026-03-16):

# Pololu 50:1 Micro Metal Gearmotor HP 6V with 12 CPR Encoder, Side Connector

> **Source:** [Pololu Product Page](https://www.pololu.com/product/4844)
> **Category:** Micro Metal Gearmotors

---

## Overview

This is a miniature brushed DC metal gearmotor with a gearbox cross section of 10×12 mm and a 9 mm long, 3 mm diameter D-shaped gearbox output shaft. It features an integrated two-channel incremental Hall effect encoder that senses the rotation of a magnetic disk on the rear protrusion of the motor shaft.

The encoder is connected via a **6-pin JST SH-style male connector** oriented perpendicularly to the motor (side connector), providing versatile mounting options.

## Key Specifications

| Parameter | Value |
|---|---|
| **Motor/brush type** | HP 6V: high-power 6V with precious metal brushes |
| **Gear ratio** | 51.45:1 (nominally 50:1) |
| **Operating voltage** | 6V |
| **No-load speed** | ~590 RPM |
| **No-load current** | ~100 mA |
| **Stall torque** | ~0.86 kg·cm (11 oz·in) |
| **Stall current** | ~1.6 A |
| **Encoder resolution** | 12 CPR (motor shaft) / ~617 CPR (gearbox output shaft) |

> **Note:** Stall torque and stall current specifications are theoretical values; stalls could damage the motor or gearbox.

## Gearbox Details

- **Cross section:** 10 × 12 mm
- **Output shaft:** 9 mm long, 3 mm diameter, D-shaped
- **Gearbox type:** Metal gears with high-durability steel plates

## Encoder Details

- **Type:** Two-channel incremental Hall effect encoder
- **Resolution:** 12 counts per revolution (CPR) of the motor shaft
- **Gearbox output CPR:** ~617 CPR (12 CPR × 51.45)
- **Connector:** 6-pin JST SH-style male connector (side-entry)
- **Operating voltage:** 2.7V – 18V

### Encoder Pinout (6-pin JST SH connector)

| Pin | Function |
|-----|---|
| 1 | Motor power (connects to one motor terminal) |
| 2 | Encoder output B |
| 3 | Encoder Vcc (2.7V – 18V) |
| 4 | Encoder GND |
| 5 | Encoder output A |
| 6 | Motor power (connects to other motor terminal) |

## Dimensions

- **Gearbox cross section:** 10 × 12 mm
- **Output shaft length:** 9 mm
- **Output shaft diameter:** 3 mm (D-shaped)

## Accessories

Compatible accessories include:

- Motor brackets for micro metal gearmotors
- Wheels (various sizes, e.g., 32×7mm)
- Motor connector shims for cable connections
- Compatible cables sold separately in various lengths

## Notes

- Cables for the side connector are sold separately
- The side connector orientation offers versatile mounting options compared to back-entry versions
- Extended motor shaft version is required for use with separate encoder kits

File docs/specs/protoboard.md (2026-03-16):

# ProtoBoard — Rectangle 2, Double Sided

> **Manufacturer:** DFRobot
> **Part Number:** FIT0203
> **Source:** [Core Electronics](https://core-electronics.com.au/protoboard-rectangle-2-double-sided.html) / [DFRobot](https://www.dfrobot.com/)

---

## Overview

A double-sided prototyping board designed for quickly prototyping stackable circuits. Features standard 0.1″ (2.54mm) hole spacing compatible with through-hole components and standard headers.

## Specifications

| Parameter | Value |
|---|---|
| **Dimensions** | 58mm × 78mm (approx. 2.28″ × 3.07″) |
| **Hole spacing** | 0.1″ (2.54mm) standard pitch |
| **Hole diameter** | ~1mm |
| **Total holes** | 22 × 26 = 572 pads |
| **Circuit pattern** | Pad Per Hole (Square) |
| **Sides** | Double-sided |
| **Mounting holes** | 4× 3mm diameter |

## Features

- Standard 0.1″ (2.54mm) pitch hole spacing
- Double-sided copper pads
- Compatible with through-hole components
- Four mounting holes for mechanical fixing
- Pad-per-hole (square) circuit pattern — no connected traces, each pad is isolated
- Good quality FR4 PCB material

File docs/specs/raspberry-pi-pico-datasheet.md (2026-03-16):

# Raspberry Pi Pico Datasheet

> **Source:** [Raspberry Pi Pico Datasheet (PDF)](https://datasheets.raspberrypi.com/pico/pico-datasheet.pdf)
> **Build Date:** 2024-10-15
> **© 2020–2024 Raspberry Pi Ltd**

---

## 1. About Raspberry Pi Pico

Raspberry Pi Pico is a microcontroller board based on the Raspberry Pi RP2040 microcontroller chip. It has been designed to be a low cost yet flexible development platform for RP2040.

### Key Features

- **RP2040 microcontroller** with 2MB Flash
- **Micro-USB B** port for power and data (and for reprogramming the Flash)
- **40-pin** 21×51 'DIP' style 1mm thick PCB with 0.1″ through-hole pins and edge castellations
  - Exposes 26 multi-function 3.3V GPIO
  - 23 GPIO are digital-only and 3 are ADC capable
  - Can be surface mounted as a module
- **3-pin ARM Serial Wire Debug (SWD)** port
- Simple yet highly flexible power supply architecture
  - Various options for powering from micro-USB, external supplies or batteries
- High quality, low cost, high availability
- Comprehensive SDK, software examples and documentation

### RP2040 Highlights

- Dual-core Cortex M0+ at up to 133MHz (on-chip PLL for variable core frequency)
- 264kB multi-bank high performance SRAM
- External Quad-SPI Flash with eXecute In Place (XIP) and 16kB on-chip cache
- High performance full-crossbar bus fabric
- On-board USB1.1 (device or host)
- 30 multi-function GPIO (4 can be used for ADC)
  - 1.8–3.3V IO Voltage (**Pico IO voltage is fixed at 3.3V**)
- 12-bit 500ksps Analogue to Digital Converter (ADC)
- Digital peripherals:
  - 2× UART, 2× I2C, 2× SPI, 16× PWM channels
  - 1× Timer with 4 alarms, 1× Real Time Counter
- 2× Programmable IO (PIO) blocks, 8 state machines total
  - Flexible, user-programmable high-speed IO
  - Can emulate interfaces such as SD Card and VGA

### Design Files

| Resource | Description |
|---|---|
| Schematic | Full schematic in Appendix B; also distributed alongside layout files |
| Layout | Full CAD files (Cadence Allegro PCB Editor format) |
| STEP 3D | 3D model for visualization and fit check |
| Fritzing | Fritzing part for breadboard layouts |

---

## 2. Mechanical Specification

Raspberry Pi Pico is a single-sided **51×21mm**, 1mm thick PCB with a micro-USB port overhanging the top edge and dual castellated/through-hole pins around the remaining edges.

- **40 main user pins** on a 2.54mm (0.1″) pitch grid with 1mm holes
- Compatible with veroboard and breadboard
- **4× 2.1mm (± 0.05mm)** drilled mounting holes

### 2.1. Pico Pinout

The Pico pinout directly brings out as much of the RP2040 GPIO and internal circuitry function as possible.

#### Internal GPIO Usage

| GPIO | Direction | Function |
|---|---|---|
| GPIO29 | Input | ADC mode (ADC3) — measures VSYS/3 |
| GPIO25 | Output | Connected to user LED |
| GPIO24 | Input | VBUS sense — high if VBUS is present |
| GPIO23 | Output | Controls on-board SMPS Power Save pin |

#### Other Pins (40-pin interface)

| Pin # | Name | Description |
|---|---|---|
| 40 | VBUS | 5V from micro-USB port (0V if USB not connected) |
| 39 | VSYS | Main system input voltage (1.8V to 5.5V) |
| 37 | 3V3_EN | SMPS enable pin (pulled high via 100kΩ to VSYS; short low to disable 3.3V) |
| 36 | 3V3 | 3.3V supply from on-board SMPS (max ~300mA recommended external load) |
| 35 | ADC_VREF | ADC power supply/reference voltage (filtered from 3.3V) |
| 33 | AGND | Analog ground reference for GPIO26–29 |
| 30 | RUN | RP2040 enable pin (~50kΩ internal pull-up to 3.3V; short low to reset) |

#### Test Points

| Test Point | Function |
|---|---|
| TP1 | Ground (close coupled for differential USB) |
| TP2 | USB DM |
| TP3 | USB DP |
| TP4 | GPIO23/SMPS PS pin (do not use) |
| TP5 | GPIO25/LED (not recommended for external use) |
| TP6 | BOOTSEL |

### 2.3. Recommended Operating Conditions

| Parameter | Value |
|---|---|
| Operating Temp Max | 85°C (including self-heating) |
| Operating Temp Min | -20°C |
| VBUS | 5V ± 10% |
| VSYS Min | 1.8V |
| VSYS Max | 5.5V |
| Recommended max ambient | 70°C |

---

## 3. Electrical Specification

### 3.1. Power Consumption

Power consumption measurements are from VBUS at 5V for three typical Pico devices with various software use cases.

#### DORMANT Mode

The lowest power state. Typical VBUS current:

| Temperature | Current |
|---|---|
| -25°C | ~1.2 mA |
| 25°C | ~0.8 mA |
| 85°C | ~1.4 mA |

#### SLEEP Mode

Low power state with some clock infrastructure alive:

| Temperature | Current |
|---|---|
| -25°C | ~1.4 mA |
| 25°C | ~1.3 mA |
| 85°C | ~1.9 mA |

#### BOOTSEL Mode (USB idle)

| Temperature | Current |
|---|---|
| -25°C | ~9.4 mA |
| 25°C | ~8.7 mA |
| 85°C | ~9.0 mA |

#### BOOTSEL Mode (USB active)

| Temperature | Current |
|---|---|
| -25°C | ~10.5 mA |
| 25°C | ~9.9 mA |
| 85°C | ~10.1 mA |

#### Popcorn Demo (VGA, SD card, I2S audio)

| Temperature | Average | Maximum |
|---|---|---|
| -25°C | ~85.6 mA | ~91.6 mA |
| 25°C | ~86.5 mA | ~91.6 mA |
| 85°C | ~88.0 mA | ~92.8 mA |

---

## 4. Applications Information

### 4.1. Programming the Flash

- **USB method:** Hold BOOTSEL while powering up → Pico appears as USB Mass Storage Device → drag `.uf2` file onto it
- **SWD method:** Use Serial Wire Debug port to load and run code without button presses
- USB boot code is stored in ROM and cannot be overwritten

### 4.2. General Purpose I/O

- Pico GPIO is powered from the on-board 3.3V rail (fixed at 3.3V)
- 26 of 30 possible RP2040 GPIO pins exposed
- GPIO0–GPIO22: digital only
- GPIO26–28: digital or ADC (software selectable)

> **Note:** ADC-capable GPIO26–29 have an internal reverse diode to VDDIO (3V3). Input voltage must not exceed VDDIO + ~300mV. If RP2040 is unpowered, voltage applied to these pins will leak through the diode. Normal digital GPIO 0–25 do not have this restriction.

### 4.3. Using the ADC

- RP2040 ADC uses its own power supply as reference (no on-board reference)
- ADC_AVDD generated from 3.3V via R-C filter (201Ω into 2.2μF)
- Inherent offset of ~30mV due to ADC current draw through the filter resistor
- **Tip:** Drive GPIO23 high to force SMPS into PWM mode, reducing ripple on ADC supply
- **Tip:** For improved performance, connect an external 3.0V shunt reference (e.g., LM4040) to ADC_VREF

### 4.4. Powerchain

- **VBUS** → Schottky diode (D1) → **VSYS** → RT6150 buck-boost SMPS → **3.3V**
- VSYS is R-C filtered and divided by 3, monitorable on ADC channel 3 (crude battery monitor)
- Buck-boost SMPS maintains 3.3V from ~1.8V to 5.5V input

#### GPIO23 — Power Save Control

| GPIO23 State | SMPS Mode | Efficiency | Ripple |
|---|---|---|---|
| Low (default) | PFM (Pulse Frequency Modulation) | High at light loads | Higher |
| High | PWM (Pulse Width Modulation) | Lower at light loads | Lower |

### 4.5. Powering Pico

1. **USB only:** Plug in micro-USB. Can short VBUS to VSYS to eliminate Schottky diode drop.
2. **External supply only:** Connect to VSYS (1.8V to 5.5V). Do not use USB.
3. **Dual supply (diode OR):** Feed second supply into VSYS via another Schottky diode.
4. **Dual supply (P-FET OR):** Use P-channel MOSFET (e.g., DMG2305UX) for better efficiency — gate controlled by VBUS, disconnects secondary source when VBUS is present.

> **Important:** If using USB Host mode, you must provide 5V to the VBUS pin.

> **Caution:** Lithium-Ion cells must have adequate protection against over-discharge, over-charge, and overcurrent.

### 4.6. Using a Battery Charger

A 'Power Path' type charger can seamlessly manage swapping between powering from battery or input source. Feed VBUS to the charger input and VSYS from the charger output via a P-FET arrangement.

### 4.7. USB

- RP2040 has an integrated USB1.1 PHY and controller (Device or Host mode)
- Pico adds two 27Ω external resistors and a standard micro-USB port

### 4.8. Debugging

- 3-pin SWD debug header on the lower edge of the board
- RP2040 has internal pull-ups on SWDIO and SWCLK (~60kΩ each)

---

## Appendix A: Availability

Raspberry Pi guarantees availability of Raspberry Pi Pico until at least **January 2028**.

### Ordering Codes

| Model | Order Code | RRP |
|---|---|-----|
| Raspberry Pi Pico | SC0915 / SC0916 | US$4.00 |
| Raspberry Pi Pico H | SC0917 | US$5.00 |

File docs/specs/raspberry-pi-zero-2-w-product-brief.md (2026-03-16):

# Raspberry Pi Zero 2 W — Product Brief

> **Manufacturer:** Raspberry Pi Ltd
> **Published:** April 2024
> **Product Page:** [raspberrypi.com/products/raspberry-pi-zero-2-w](https://www.raspberrypi.com/products/raspberry-pi-zero-2-w/)

---

## Overview

Raspberry Pi Zero 2 W is the latest product in the most affordable range of single-board computers. The successor to the breakthrough Raspberry Pi Zero W, Raspberry Pi Zero 2 W is a form factor–compatible drop-in replacement for the original board.

The board incorporates a **quad-core 64-bit Arm Cortex-A53 CPU**, clocked at 1GHz. At its heart is a Raspberry Pi **RP3A0** system-in-package (SiP), integrating a Broadcom BCM2710A1 die with 512MB of LPDDR2 SDRAM.

### Performance vs Original Zero

| Metric | Improvement |
|---|---|
| Single-threaded performance | **40% faster** |
| Multi-threaded performance | **5× faster** |
| Approximate performance vs Pi 3B | ~80% |

---

## Specifications

| Parameter | Value |
|---|---|
| **Form factor** | 65mm × 30mm |
| **Processor** | Broadcom BCM2710A1, quad-core 64-bit SoC (Arm Cortex-A53 @ 1GHz) |
| **System-in-Package** | Raspberry Pi RP3A0 (integrates BCM2710A1 + 512MB LPDDR2) |
| **Memory** | 512MB LPDDR2 SDRAM |
| **GPU** | VideoCore IV |
| **Wireless LAN** | 2.4GHz IEEE 802.11 b/g/n, onboard antenna |
| **Bluetooth** | Bluetooth 4.2, BLE (Bluetooth Low Energy) |
| **Modular compliance** | Certified |
| **USB** | 1× Micro USB 2.0 OTG (data) |
| **Power input** | 1× Micro USB (5V DC, 2.5A recommended) |
| **GPIO** | HAT-compatible 40-pin I/O header footprint (unpopulated) |
| **Storage** | microSD card slot |
| **Video output** | Mini HDMI port (up to 1080p) |
| **Camera** | CSI-2 camera connector (adapter cable required) |
| **Composite video** | Available via `TV` test point on underside of board |
| **Video decode** | H.264, MPEG-4 decode (1080p30) |
| **Video encode** | H.264 encode (1080p30) |
| **Graphics** | OpenGL ES 1.1, 2.0 |
| **Operating temperature** | -20°C to +70°C |
| **Production lifetime** | Until at least **January 2030** |

---

## Power Consumption

| State | Typical Current @ 5V | Power |
|---|---|---|
| **Idle** | ~100–280 mA | ~0.5–1.4W |
| **Bare-board active** | ~350 mA | ~1.75W |
| **Full CPU stress (4 cores)** | ~500–580 mA | ~2.3–3.0W |

> **Note:** A 5V power supply with a minimum of **2.5A** is recommended for stable operation, especially when connecting peripherals.

### Power Optimization Tips

- Disable unused CPU cores to reduce consumption
- Disable HDMI output (`tvservice -o`) when not needed
- Disable onboard LED via `/boot/config.txt`

---

## GPIO Header (40-Pin)

The Raspberry Pi Zero 2 W uses the standard Raspberry Pi 40-pin GPIO header layout (HAT-compatible). The header footprint is **unpopulated** — you'll need to solder your own header pins.

### Pin Layout

```
                    3V3  (1) (2)  5V
          GPIO2/SDA (3) (4)  5V
          GPIO3/SCL (5) (6)  GND
            GPIO4   (7) (8)  GPIO14/TXD
              GND   (9) (10) GPIO15/RXD
           GPIO17  (11) (12) GPIO18/PCM_CLK
           GPIO27  (13) (14) GND
           GPIO22  (15) (16) GPIO23
              3V3  (17) (18) GPIO24
  GPIO10/SPI_MOSI  (19) (20) GND
   GPIO9/SPI_MISO  (21) (22) GPIO25
  GPIO11/SPI_SCLK  (23) (24) GPIO8/SPI_CE0
              GND  (25) (26) GPIO7/SPI_CE1
    GPIO0/ID_SDA   (27) (28) GPIO1/ID_SCL
            GPIO5  (29) (30) GND
            GPIO6  (31) (32) GPIO12/PWM0
      GPIO13/PWM1  (33) (34) GND
  GPIO19/PCM_FS    (35) (36) GPIO16
           GPIO26  (37) (38) GPIO20/PCM_DIN
              GND  (39) (40) GPIO21/PCM_DOUT
```

### GPIO Summary

| Resource | Count / Details |
|---|---|
| **Total GPIO pins** | 26 general-purpose I/O lines |
| **3.3V power** | 2 pins (pin 1, 17) |
| **5V power** | 2 pins (pin 2, 4) |
| **Ground** | 8 pins (pin 6, 9, 14, 20, 25, 30, 34, 39) |
| **I²C** | 1 bus — SDA (GPIO2), SCL (GPIO3) |
| **SPI** | 1 bus — MOSI (GPIO10), MISO (GPIO9), SCLK (GPIO11), CE0 (GPIO8), CE1 (GPIO7) |
| **UART** | 1 port — TXD (GPIO14), RXD (GPIO15) |
| **PWM** | 2 channels — PWM0 (GPIO12/18), PWM1 (GPIO13/19) |
| **PCM/I²S** | CLK (GPIO18), FS (GPIO19), DIN (GPIO20), DOUT (GPIO21) |
| **1-Wire** | GPIO4 (default) |
| **ID EEPROM** | SDA (GPIO0), SCL (GPIO1) — for HAT identification |

### GPIO Electrical Characteristics

| Parameter | Value |
|---|---|
| Logic level | 3.3V |
| Max current per GPIO pin | 16 mA |
| Max total current (all GPIO combined) | 50 mA |

> **Warning:** GPIO pins are **3.3V only**. Connecting 5V signals directly to GPIO pins will damage the board.

---

## Board Interfaces & Connectors

### Micro USB Ports (×2)

| Port | Function |
|---|---|
| **USB PWR** | 5V power input only |
| **USB DATA** | USB 2.0 OTG — data transfers, USB devices, or USB gadget mode |

### Mini HDMI Port

- Full HDMI output up to 1080p60
- Requires Mini HDMI to HDMI adapter cable
- HDMI CEC supported

### CSI-2 Camera Connector

- 22-pin FFC connector (smaller than full-size Pi)
- Requires a **Zero-specific CSI adapter cable** (different from standard Pi camera cable)
- Supports Raspberry Pi Camera Modules

### microSD Card Slot

- Push-push type
- Supports SD, SDHC, SDXC cards
- Used for OS boot and storage

---

## Test Points & Solder Pads

The Zero 2 W exposes several test points on the underside of the board:

| Test Point | Function | Description |
|---|---|---|
| **TV** | Composite video | Solder a wire here for composite video output |
| **RUN** | Hardware reset | Momentarily short to GND to reset the Pi |
| **USB_DP** | USB Data+ | USB differential signal |
| **USB_DM** | USB Data− | USB differential signal |
| **5V** | 5V supply | 5V power rail |
| **3V3** | 3.3V supply | 3.3V regulated rail |
| **1V8** | 1.8V supply | 1.8V internal rail |
| **CORE** | Core voltage | CPU core voltage |
| **WL_ON** | Wireless LAN enable | WiFi control |
| **BT_ON** | Bluetooth enable | Bluetooth control |
| **OTG** | USB OTG ID | USB OTG identification |
| **STATUS_LED** | Activity LED | Board activity LED control |

### Enabling Composite Video

1. Solder a wire to the `TV` test point (video signal) and a nearby `GND` pad
2. Edit `/boot/config.txt`:
   ```
   enable_tvout=1
   sdtv_mode=0      # 0=NTSC, 1=Japanese NTSC, 2=PAL, 3=Brazilian PAL
   sdtv_aspect=1    # 1=4:3, 2=14:9, 3=16:9
   ```
3. Optionally add `hdmi_ignore_hotplug=1` to force composite output

### Using the RUN (Reset) Pad

- Solder a momentary push-button between `RUN` and `GND`
- Pressing the button resets the Pi (equivalent to power cycle)
- **Caution:** Resetting during write operations may corrupt the SD card

---

## Wireless & Networking

### WiFi

| Parameter | Value |
|---|---|
| Standard | IEEE 802.11 b/g/n |
| Frequency | 2.4 GHz |
| Antenna | Onboard PCB antenna |
| Security | WPA/WPA2/WPA3 |

### Bluetooth

| Parameter | Value |
|---|---|
| Version | Bluetooth 4.2 |
| BLE | Bluetooth Low Energy supported |
| Profiles | Various (A2DP, HID, etc.) |

---

## Multimedia

### Video Output

| Feature | Specification |
|---|---|
| HDMI | Mini HDMI, up to 1080p60 |
| Composite | Via `TV` test point (requires config) |
| HDMI CEC | Supported |

### Video Decode / Encode

| Codec | Capability |
|---|---|
| H.264 decode | 1080p30 |
| MPEG-4 decode | 1080p30 |
| H.264 encode | 1080p30 |

### Graphics

| Feature | Specification |
|---|---|
| GPU | VideoCore IV |
| OpenGL ES | 1.1, 2.0 |

---

## Physical Specification

### Dimensions

```
        ┌──────────────── 65mm ────────────────┐
        │                                       │
  30mm  │     ┌──┐                        ┌──┐  │
        │     │  │  Mounting holes (×4)   │  │  │  3.5mm
        │     └──┘                        └──┘  │  (board
        │                                       │   height)
        └───────────────────────────────────────┘
```

| Dimension | Value |
|---|---|
| Length | 65 mm |
| Width | 30 mm |
| Height (max) | ~3.5 mm (excluding connectors) |
| Mounting holes | 4× (corner locations) |
| Mounting hole spacing (length) | 58 mm (between centers) |
| Mounting hole spacing (width) | 23 mm (between centers) |
| Mounting hole offset from edges | 3.5 mm |

### Key Component Positions (from left edge)

| Distance | Component |
|---|---|
| 12.4 mm | First mounting hole center |
| 41.4 mm | Camera connector center |
| 54.0 mm | Second mounting hole center |

---

## Supported Operating Systems

- **Raspberry Pi OS** (32-bit and 64-bit) — recommended
- Ubuntu Server
- DietPi
- Various other Linux distributions with ARM64 support

> **Note:** 64-bit OS recommended to take full advantage of the Cortex-A53 architecture.

---

## Comparison with Other Pi Zero Models

| Feature | Zero | Zero W | **Zero 2 W** |
|---|---|---|---|
| Processor | BCM2835 (1 core, 1GHz) | BCM2835 (1 core, 1GHz) | **BCM2710A1 (4 cores, 1GHz)** |
| RAM | 512MB | 512MB | **512MB** |
| WiFi | No | 802.11n | **802.11n** |
| Bluetooth | No | BT 4.1, BLE | **BT 4.2, BLE** |
| Form factor | 65×30mm | 65×30mm | **65×30mm** |
| GPIO | 40-pin | 40-pin | **40-pin** |
| USB | Micro USB OTG | Micro USB OTG | **Micro USB OTG** |
| Video | Mini HDMI | Mini HDMI | **Mini HDMI** |
| Camera | CSI-2 | CSI-2 | **CSI-2** |

---

## Design Resources

- [Product Brief (PDF)](https://datasheets.raspberrypi.com/rpizero2/raspberry-pi-zero-2-w-product-brief.pdf)
- [Reduced Schematics](https://datasheets.raspberrypi.com/rpizero2/raspberry-pi-zero-2-w-reduced-schematics.pdf)
- [Mechanical Drawing](https://datasheets.raspberrypi.com/rpizero2/raspberry-pi-zero-2-w-mechanical-drawing.pdf)
- [Test Pad Specification](https://datasheets.raspberrypi.com/rpizero2/raspberry-pi-zero-2-w-test-pads.pdf)
- [BCM2837 ARM Peripherals Specification](https://datasheets.raspberrypi.com/bcm2835/bcm2835-peripherals.pdf) (functionally equivalent to BCM2710A1)
- [Compliance Documentation](https://pip.raspberrypi.com)

---

## Warnings

- Any external power supply must comply with relevant regulations and standards applicable in the country of intended use
- Operate in a well-ventilated environment; if used inside a case, the case should not be covered
- Place on a stable, flat, non-conductive surface during use
- Connection of incompatible devices may affect compliance, damage the unit, and void the warranty
- All peripherals must comply with relevant standards for the country of use
- Cables and connectors of all peripherals must have adequate insulation

## Safety Instructions

- Do not expose to water or moisture, or place on a conductive surface whilst in operation
- Do not expose to heat from any source; designed for reliable operation at normal ambient temperatures
- Take care to avoid mechanical or electrical damage to the printed circuit board and connectors
- While powered, avoid handling the PCB, or only handle by the edges to minimise ESD risk

---

*The terms HDMI, HDMI High-Definition Multimedia Interface, and the HDMI Logo are trademarks or registered trademarks of HDMI Licensing Administrator, Inc.*

*Raspberry Pi is a trademark of Raspberry Pi Ltd*

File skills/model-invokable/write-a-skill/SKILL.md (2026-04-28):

---
name: write-a-skill
description: Create new agent skills with proper structure, progressive disclosure, and bundled resources. Use when user wants to create, write, or build a new skill.
---

# Writing Skills

## Process

1. **Gather requirements** - ask user about:
   - What task/domain does the skill cover?
   - What specific use cases should it handle?
   - Does it need executable scripts or just instructions?
   - Any reference materials to include?

2. **Draft the skill** - create:
   - SKILL.md with concise instructions
   - Additional reference files if content exceeds 500 lines
   - Utility scripts if deterministic operations needed

3. **Review with user** - present draft and ask:
   - Does this cover your use cases?
   - Anything missing or unclear?
   - Should any section be more/less detailed?

## Skill Structure

```
skill-name/
├── SKILL.md           # Main instructions (required)
├── REFERENCE.md       # Detailed docs (if needed)
├── EXAMPLES.md        # Usage examples (if needed)
└── scripts/           # Utility scripts (if needed)
    └── helper.js
```

## SKILL.md Template

```md
---
name: skill-name
description: Brief description of capability. Use when [specific triggers].
---

# Skill Name

## Quick start

[Minimal working example]

## Workflows

[Step-by-step processes with checklists for complex tasks]

## Advanced features

[Link to separate files: See [REFERENCE.md](REFERENCE.md)]
```

## Description Requirements

The description is **the only thing your agent sees** when deciding which skill to load. It's surfaced in the system prompt alongside all other installed skills. Your agent reads these descriptions and picks the relevant skill based on the user's request.

**Goal**: Give your agent just enough info to know:

1. What capability this skill provides
2. When/why to trigger it (specific keywords, contexts, file types)

**Format**:

- Max 1024 chars
- Write in third person
- First sentence: what it does
- Second sentence: "Use when [specific triggers]"

**Good example**:

```
Extract text and tables from PDF files, fill forms, merge documents. Use when working with PDF files or when user mentions PDFs, forms, or document extraction.
```

**Bad example**:

```
Helps with documents.
```

The bad example gives your agent no way to distinguish this from other document skills.

## When to Add Scripts

Add utility scripts when:

- Operation is deterministic (validation, formatting)
- Same code would be generated repeatedly
- Errors need explicit handling

Scripts save tokens and improve reliability vs generated code.

## When to Split Files

Split into separate files when:

- SKILL.md exceeds 100 lines
- Content has distinct domains (finance vs sales schemas)
- Advanced features are rarely needed

## Behavioral Floor

Every skill in this framework runs on top of the four principles in the user-level `AGENTS.md` (Think Before Coding, Simplicity First, Surgical Changes, Goal-Driven Execution). A new skill must not contradict the floor. If a skill needs to override it (e.g. an architecture skill that proposes refactors beyond the immediate request), state the override explicitly in the skill body.

Default placement:
- **`skills/model-invokable/`** — auto-fires on relevant prompts. Trigger `description` must be tight enough that auto-selection doesn't fire on adjacent topics.
- **`skills/slash-only/`** — set `disable-model-invocation: true` in frontmatter. Use for stylistic modes, one-shot prompts, and heavy workflows that should only run on explicit invocation.
- **`skills/dormant/`** — leave unregistered in `.claude-plugin/plugin.json`. Stored but inert.

## Review Checklist

After drafting, verify:

- [ ] Description includes triggers ("Use when...")
- [ ] SKILL.md under 100 lines
- [ ] No time-sensitive info
- [ ] Consistent terminology
- [ ] Concrete examples included
- [ ] References one level deep
- [ ] Does not contradict the four principles in `AGENTS.md` (or states the override)
- [ ] Placed in the right bucket (`model-invokable/`, `slash-only/`, `dormant/`)
- [ ] Registered in `.claude-plugin/plugin.json` if it should be active

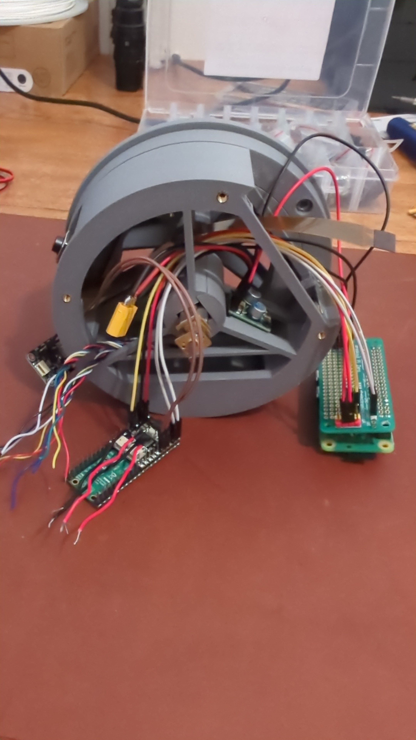
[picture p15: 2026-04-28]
images/wip_stator_top_view.jpg

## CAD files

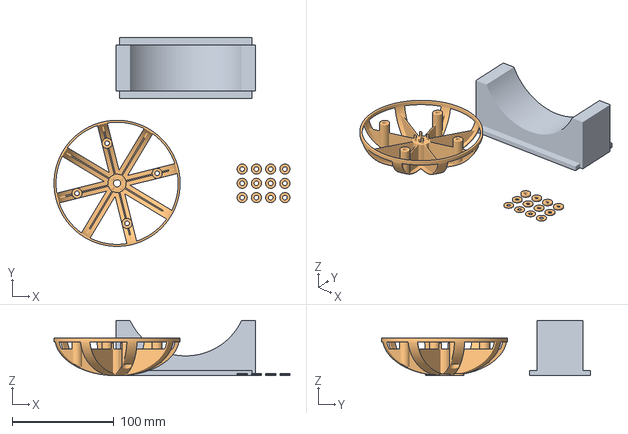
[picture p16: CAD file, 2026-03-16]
cad/wheel_v7.3mf
232.0 x 205.3 x 54.5 mm
cradle_v2.stl
wheel_v11.stl

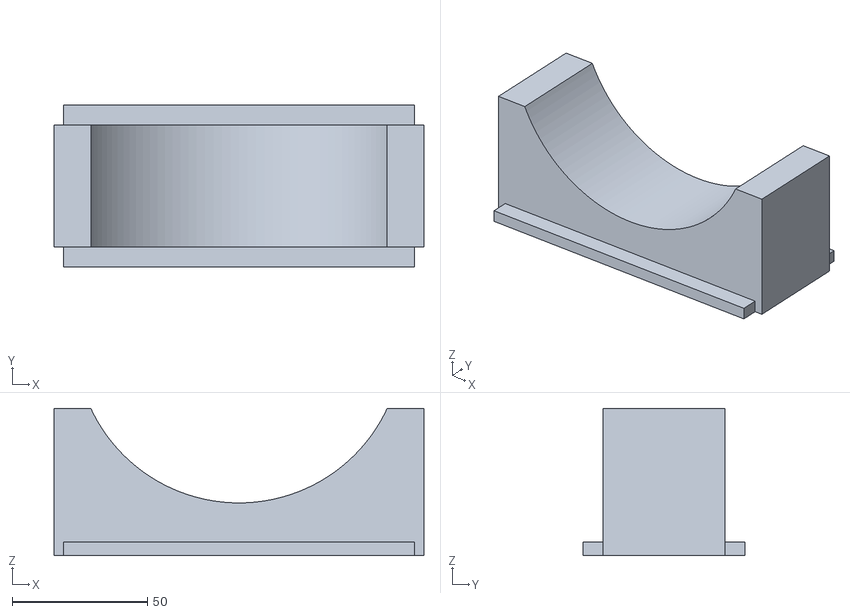
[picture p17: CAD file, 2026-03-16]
cad/cradle.stl
137.0 x 60.0 x 54.5

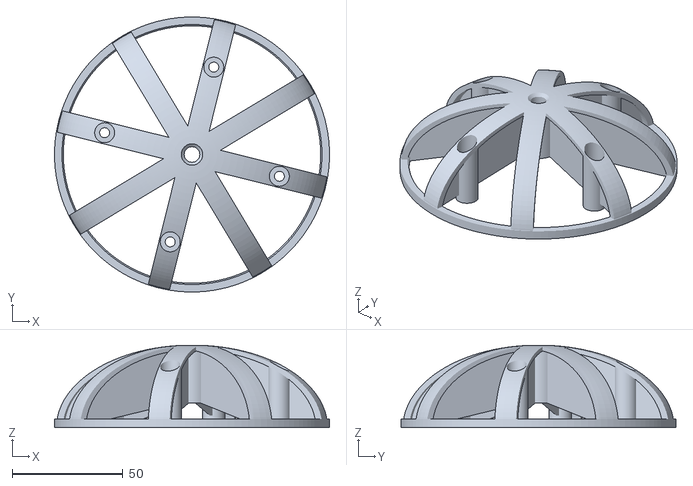
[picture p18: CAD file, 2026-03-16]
cad/wheel_v13.stl
124.0 x 124.0 x 37.1

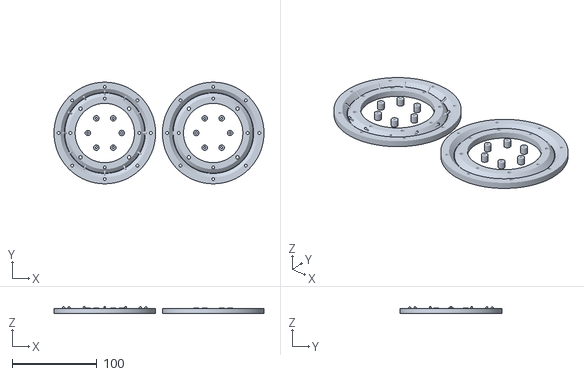
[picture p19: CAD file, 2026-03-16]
cad/slewing_bearing_v6_half_plate.stl
248.0 x 120.0 x 8.59

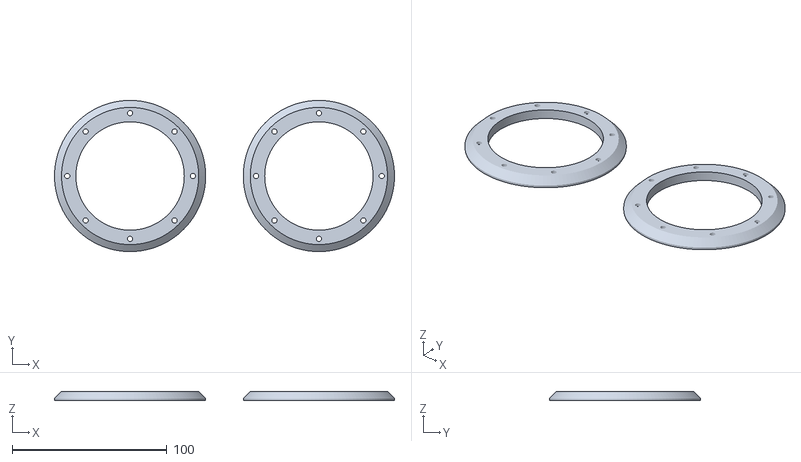
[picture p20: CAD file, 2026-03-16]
cad/slewing_bearing_inner_ring_v1.stl
219.7 x 97.7 x 6.00

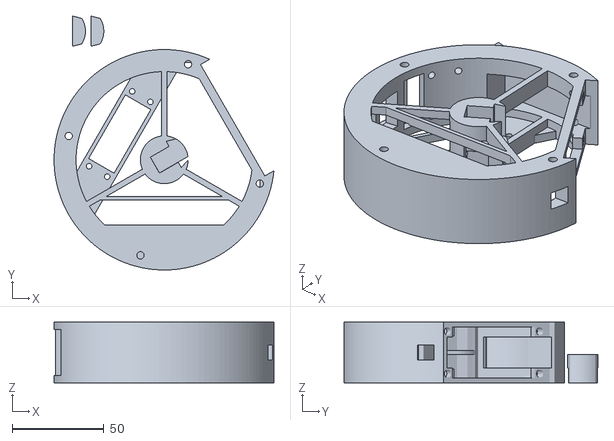
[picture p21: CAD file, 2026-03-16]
cad/stator_ring_v13.stl
119.7 x 138.2 x 33.0

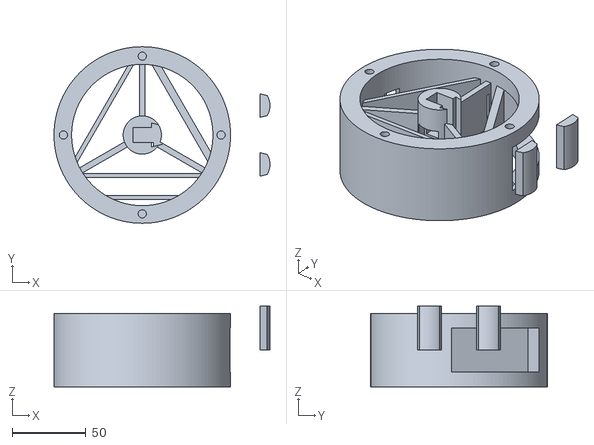
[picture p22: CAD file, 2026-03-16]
cad/stator_ring_1.stl
146.8 x 120.0 x 55.0

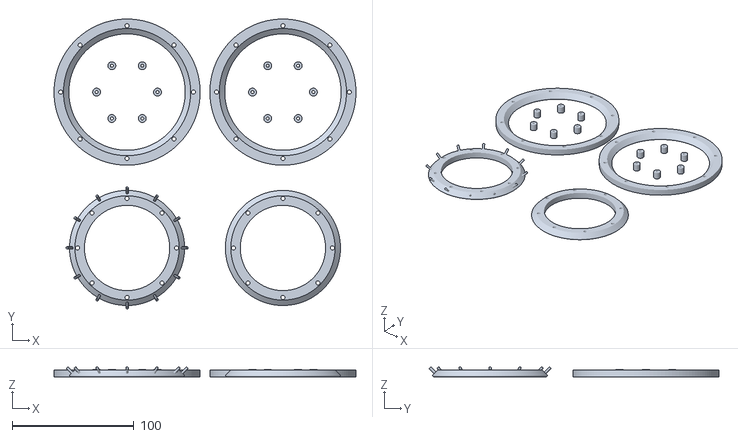
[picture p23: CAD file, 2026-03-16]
cad/slewing_bearing_flexible.stl
248.0 x 238.1 x 8.59

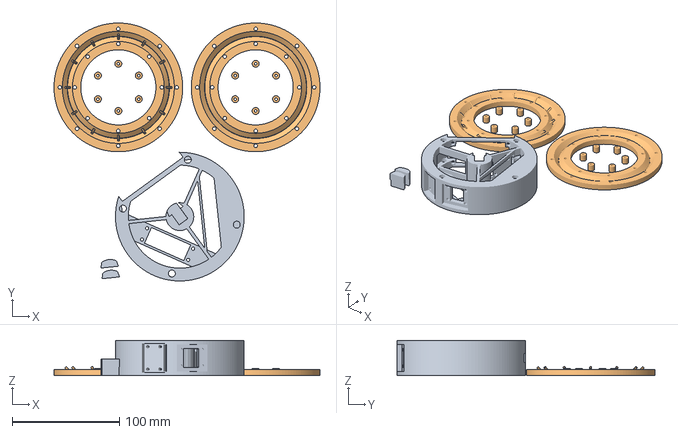
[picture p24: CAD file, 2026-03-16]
cad/stator_ring_v4.3mf
248.0 x 240.5 x 33.0 mm
stator_ring_v12.stl
slewing_bearing_v4_half_plate.stl

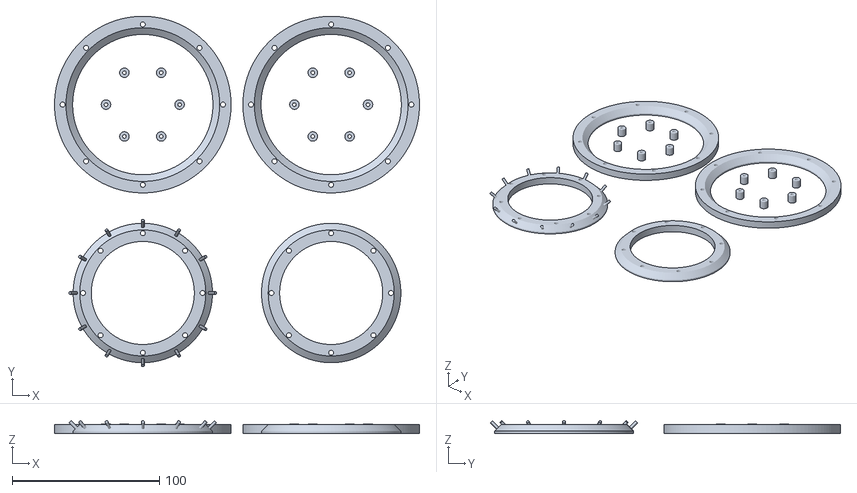
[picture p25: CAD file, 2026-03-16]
cad/slewing_bearing_v4.stl
248.0 x 238.1 x 8.59

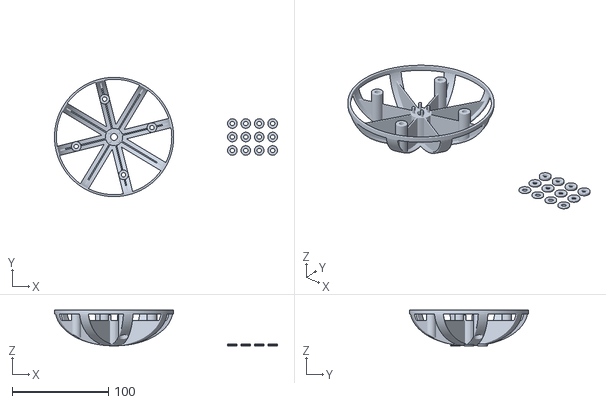
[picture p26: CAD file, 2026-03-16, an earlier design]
cad/archive/wheel_v11.stl
232.0 x 124.0 x 37.2

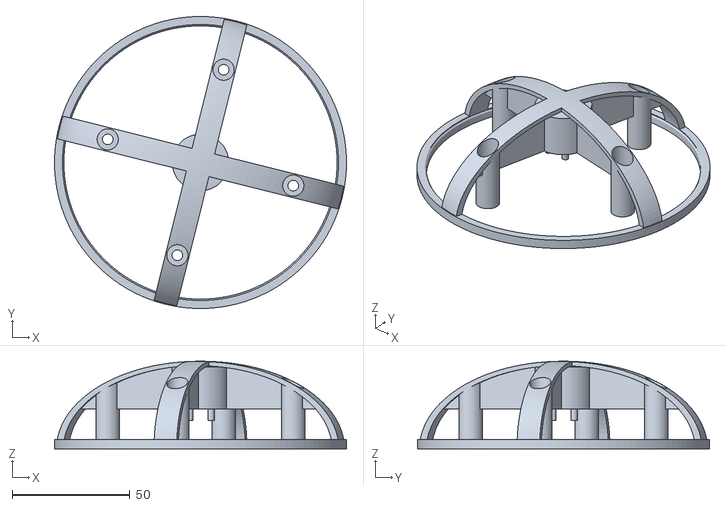
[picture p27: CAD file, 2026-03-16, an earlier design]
cad/wheel_v2.stl
124.0 x 124.0 x 37.2

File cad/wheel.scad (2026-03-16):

// Required variable inherited from the main file for positional logic
shroud_width = 32;

// --- NEW SHAPE CONTROL VARIABLES ---
partial_sphere_percent    = 8;      // [0:100] 100% = Full solid shell. 0% = Naked.
partial_sphere_segments   = 8;      // Number of parallel struts/segments radiating from center.
rotor_ring_height         = 4;      // The bottom rim height that remains solid
rotor_radius              = 62;     // Overall radius of the wheel
rotor_elongation          = 0.60;   // 1.0 = perfect hemisphere. > 1.0 = elongated. < 1.0 = flattened.
rotor_ls_mount_radius     = 53.6-13; // Distance from center to the lazy susan pillars
rotor_ls_pillar_extension = 0;      // Positive = pillars extend PAST the flat rim. 

// --- RIM CONTROL VARIABLES ---
rotor_rim_thickness       = 3;      // [THINNED] Reduced from 4mm
rotor_rim_height          = 4;      // How far up the inside of the sphere the thickened rim extends

// --- HEMISPHERE ROTOR PARAMETERS ---
rotor_outer_diameter = rotor_radius * 2; 
rotor_thickness      = 3;   // [THINNED] Shell wall thickness (Reduced from 3mm)
rotor_inner_diameter = rotor_outer_diameter - (rotor_thickness * 2);

// Motor Hub (Pololu Aluminum Hub Interface)
rotor_hub_outer_dia     = 18;   // [THINNED] Reduced from 24mm to save center mass
rotor_hub_z_offset      = 11;   // The gap from the open rim (Z=0) to the flat mating face
pololu_bcd              = 12.7; // Bolt Circle Diameter of the 4 M3 holes on the metal hub
pololu_hole_dia         = 3.0;  // 3mm holes for the hub mounting
pololu_hole_depth       = 10.0; // 10mm deep holes
pololu_pin_rotation     = 45;   // Rotational alignment of the 4 holes
pololu_center_clearance = 7;    // Center bore diameter to ensure motor shaft spins freely
pololu_center_depth     = 1;    // Distance the clearance bore extends downward from the hub face 
pololu_center_chamfer   = 1.5;  // Chamfer depth for the top exit hole (in mm)

// Internal Webbing (Spokes)
rotor_spoke_thickness  = 1.2;  // [THINNED] Reduced from 2mm
rotor_spoke_length     = 62;   // Distance the internal ribs extend from the center (in mm)

// Lazy Susan Mounting 
rotor_ls_hole_dia        = 4.5; // Bottom clearance hole for M4 screw threads
rotor_ls_access_hole_dia = 9.0; // Top clearance hole for screwdriver & screw head
rotor_ls_standoff_dia    = 10;  // Increased to 12mm so the 9mm access hole doesn't sever the ribs
rotor_ls_standoff_height = 6;   // Total thickness of plastic the screw bites into
rotor_ls_rotation        = -14; // Matches the stator

$fn = 120;

// ==========================================
// MODULE DEFINITIONS
// ==========================================
// The Outer Drive Shell
module HemisphereRotor() {
    // Dynamic height calculation to ensure internal structures always hit the ceiling
    max_z_reach = rotor_outer_diameter * max(1, rotor_elongation);
    
    difference() {
        union() {
            // 1. The Main Outer Shell (Elongated via scale)
            difference() {
                union() { // Group the shell and the rim so the area blocks cut both
                    difference() {
                        scale([1, 1, rotor_elongation]) sphere(d = rotor_outer_diameter);
                        scale([1, 1, rotor_elongation]) sphere(d = rotor_inner_diameter);
                        
                        // Chop off the bottom half completely so it sits flat at Z=0
                        translate([0, 0, -max_z_reach / 2])
                            cube(max_z_reach + 5, center = true);
                    }
                    
                    // Independent Thickened Rim
                    rim_extra = rotor_rim_thickness - rotor_thickness;
                    if (rim_extra > 0) {
                        rotate_extrude() {
                            polygon([
                                [rotor_outer_diameter/2 - rotor_rim_thickness, 0],                            // Bottom-Inner
                                [rotor_outer_diameter/2, 0],                                                  // Bottom-Outer
                                [rotor_outer_diameter/2, rotor_rim_height],                                   // Top-Outer
                                [rotor_outer_diameter/2 - rotor_thickness, rotor_rim_height],                 // Top-Inner (meets the shell)
                                [rotor_outer_diameter/2 - rotor_rim_thickness, rotor_rim_height - rim_extra]  // 45-deg overhang slope
                            ]);
                        }
                    }
                } // End of Shell + Rim Union
                    
                // Dynamic Shell Coverage (Constant width struts aligned to internal webbing)
                if (partial_sphere_percent < 100) {
                    rotate([0, 0, rotor_ls_rotation]) {
                        // Map the percentage directly to a linear width
                        strut_width = rotor_outer_diameter * (partial_sphere_percent / 100);
                        cut_size = rotor_outer_diameter + 10; // Padding to guarantee clean cuts

                        // Use a 2D extrusion of the negative space to cleanly cut N segments
                        translate([0, 0, rotor_ring_height])
                        linear_extrude(height = cut_size) {
                            difference() {
                                // Start with a solid circle covering the whole area
                                circle(d = cut_size);
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

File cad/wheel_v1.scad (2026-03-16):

// Required variable inherited from the main file for positional logic
shroud_width = 32;

// --- NEW SHAPE CONTROL VARIABLES ---
partial_sphere_percent    = 10;    // [0:100] 100% = Full solid shell. 0% = Naked (only border ring). 20% = Partial struts.
partial_sphere_segments   = 8;     // Number of parallel struts/segments radiating from the center. Try 4 to 8.
rotor_ring_height         = 4;     // The bottom rim height that remains solid regardless of cover percentage
rotor_radius              = 62;    // Overall radius of the wheel
rotor_elongation          = 0.60;  // 1.0 = perfect hemisphere. > 1.0 = elongated/stretched outwards. < 1.0 = flattened dome.
rotor_ls_mount_radius     = 53.6-13; // Distance from center to the lazy susan pillars (closer/further from center)
rotor_ls_pillar_extension = 0;     // Positive = pillars extend PAST the flat rim. Negative = pillars are recessed/extracted inside.

// --- RIM CONTROL VARIABLES ---
rotor_rim_thickness       = 4;     // Independent thickness of the rim at the very bottom edge (Z=0)
rotor_rim_height          = 4;     // How far up the inside of the sphere the thickened rim extends

// --- HEMISPHERE ROTOR PARAMETERS ---
rotor_outer_diameter = rotor_radius * 2; 
rotor_thickness      = 3;   // Shell wall thickness
rotor_inner_diameter = rotor_outer_diameter - (rotor_thickness * 2);

// Motor Hub (Pololu Aluminum Hub Interface)
rotor_hub_outer_dia     = 24;   // Diameter of the plastic center hub
rotor_hub_z_offset      = 11;   // The gap from the open rim (Z=0) to the flat mating face of the hub
pololu_bcd              = 12.7; // Bolt Circle Diameter of the 4 M3 holes on the metal hub
pololu_insert_dia       = 4.2;  // Hole diameter for M3 heat-set insert (Adjust to your specific inserts)
pololu_insert_depth     = 5.5;  // Depth of the hole for the insert into the plastic
pololu_pin_rotation     = 45;   // Rotational alignment of the 4 holes
pololu_center_clearance = 4;    // Center bore diameter to ensure motor shaft spins freely

// Internal Webbing (Spokes)
rotor_spoke_thickness  = 2;   
rotor_spoke_length     = 62;  // Distance the internal ribs extend from the center (in mm)

// Lazy Susan Mounting 
rotor_ls_hole_dia        = 4.5; // Bottom clearance hole for M4 screw threads
rotor_ls_access_hole_dia = 9.0; // Top clearance hole for screwdriver & screw head
rotor_ls_standoff_dia    = 10;  // Diameter of the mounting pillar
rotor_ls_standoff_height = 6;   // Total thickness of plastic the screw bites into before the head seats
rotor_ls_rotation        = -14; // Matches the stator

$fn = 120;

// ==========================================
// MODULE DEFINITIONS
// ==========================================
// The Outer Drive Shell
module HemisphereRotor() {
    // Dynamic height calculation to ensure internal structures always hit the ceiling
    max_z_reach = rotor_outer_diameter * max(1, rotor_elongation);
    
    difference() {
        union() {
            // 1. The Main Outer Shell (Elongated via scale)
            difference() {
                union() { // Group the shell and the rim so the area blocks cut both
                    difference() {
                        scale([1, 1, rotor_elongation]) sphere(d = rotor_outer_diameter);
                        scale([1, 1, rotor_elongation]) sphere(d = rotor_inner_diameter);
                        
                        // Chop off the bottom half completely so it sits flat at Z=0
                        translate([0, 0, -max_z_reach / 2])
                            cube(max_z_reach + 5, center = true);
                    }
                    
                    // Independent Thickened Rim
                    rim_extra = rotor_rim_thickness - rotor_thickness;
                    if (rim_extra > 0) {
                        rotate_extrude() {
                            polygon([
                                [rotor_outer_diameter/2 - rotor_rim_thickness, 0],                            // Bottom-Inner
                                [rotor_outer_diameter/2, 0],                                                  // Bottom-Outer
                                [rotor_outer_diameter/2, rotor_rim_height],                                   // Top-Outer
                                [rotor_outer_diameter/2 - rotor_thickness, rotor_rim_height],                 // Top-Inner (meets the shell)
                                [rotor_outer_diameter/2 - rotor_rim_thickness, rotor_rim_height - rim_extra]  // 45-deg overhang slope
                            ]);
                        }
                    }
                } // End of Shell + Rim Union
                    
                // Dynamic Shell Coverage (Constant width struts aligned to internal webbing)
                if (partial_sphere_percent < 100) {
                    rotate([0, 0, rotor_ls_rotation]) {
                        // Map the percentage directly to a linear width
                        strut_width = rotor_outer_diameter * (partial_sphere_percent / 100);
                        cut_size = rotor_outer_diameter + 10; // Padding to guarantee clean cuts

                        // Use a 2D extrusion of the negative space to cleanly cut N segments
                        translate([0, 0, rotor_ring_height])
                        linear_extrude(height = cut_size) {
                            difference() {
                                // Start with a solid circle covering the whole area
                                circle(d = cut_size);
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

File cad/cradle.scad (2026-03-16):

// ==========================================
// TESTING STAND MODULE (SUPPORT-FREE)
// ==========================================
stand_center_height  = 85;  // Height of the robot's center axis (gives 23mm ground clearance)
stand_cradle_dia     = 121; // 1mm extra clearance so the 120mm shroud drops in easily
stand_thickness      = 25;  // Narrower than the 33mm shroud to prevent rubbing
stand_base_x         = 130; // Footprint width for stability
stand_base_y         = 60;  // Footprint depth for stability

// --- NEW HEIGHT CONTROL ---
stand_support_height = 35;  // How far up the side of the robot the prongs reach from the bottom of the curve (Max is 60.5)

module TestingStand() {
    // Calculate the absolute Z height of the lowest point of the cradle curve
    cradle_bottom_z = stand_center_height - (stand_cradle_dia / 2);
    prong_top_z = cradle_bottom_z + stand_support_height;
    
    difference() {
        // Main Positive Geometry
        union() {
            // Flat Base Plate (Rests flush at Z=0)
            translate([0, 0, 2.5])
                cube([stand_base_x, stand_base_y, 5], center = true);
            
            // Upright Support Block
            translate([0, 0, stand_center_height / 2])
                cube([stand_cradle_dia + 16, stand_thickness, stand_center_height], center = true);
        }
        
        // Subtractions
        // 1. The U-Shape Cradle Cutout
        translate([0, 0, stand_center_height])
            rotate([90, 0, 0])
            cylinder(d = stand_cradle_dia, h = stand_thickness + 2, center = true, $fn=120);
            
        // 2. Dynamic Chop-off to control prong height
        // We place a massive subtraction cube directly at the exact Z-height where the prongs should end
        translate([0, 0, prong_top_z + 50])
            cube([stand_base_x + 50, stand_thickness + 2, 100], center = true);
    }
}

// Render the stand centered perfectly at the origin for slicing
TestingStand();

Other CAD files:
cad/slewing_bearing_v3.stl
cad/archive/slewing_bearing_v3.stl
cad/slewing_bearing_v5_half_plate.stl
cad/Slewing Bearing v1.scad
cad/archive/cradle_v1.stl
cad/archive/slewing_bearing_v1.stl
cad/archive/slewing_bearing_v2.stl
cad/archive/slewing_bearing_v4_half_plate.stl
cad/archive/slewing_bearing_v5_half_plate.stl
cad/archive/stator_ring_v1.3mf
cad/archive/stator_ring_v10.stl
cad/archive/stator_ring_v11.stl
cad/archive/stator_ring_v12.stl
cad/archive/stator_ring_v2.3mf
cad/archive/stator_ring_v3.3mf
cad/archive/stator_ring_v3.stl
cad/archive/stator_ring_v4.stl
cad/archive/stator_ring_v5.stl
cad/archive/stator_ring_v6.stl
cad/archive/stator_ring_v7.stl
cad/archive/stator_ring_v8.stl
cad/archive/stator_ring_v9.stl
cad/archive/wheel_v1.stl
cad/archive/wheel_v10.stl
cad/archive/wheel_v12.stl
cad/archive/wheel_v3.stl
cad/archive/wheel_v4.stl
cad/archive/wheel_v5.stl
cad/archive/wheel_v6.stl
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

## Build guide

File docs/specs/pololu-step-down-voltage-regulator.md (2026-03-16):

# Pololu 5V, 5.5A Step-Down Voltage Regulator D36V50F5

> **Source:** [Pololu Product #4091](https://www.pololu.com/product/4091)
> **Category:** Step-Down (Buck) Voltage Regulators → D36V50Fx Family

---

## Overview

The D36V50Fx family of synchronous buck (step-down) voltage regulators generates lower output voltages from input voltages as high as 50V. They are switching regulators (SMPS / DC-to-DC converters), which makes them much more efficient than linear voltage regulators, especially when the difference between the input and output voltage is large.

These regulators can typically support continuous output currents between 2A and 9A, depending on the input and output voltage.

## Key Specifications

| Parameter | Value |
|---|---|
| **Output voltage** | 5V (4% accuracy) |
| **Input voltage** | 5.5V to 50V (min input subject to dropout voltage) |
| **Typical max continuous output current** | 3.5A to 8A (varies with input voltage) |
| **Typical efficiency** | 80% to 95% |
| **Switching frequency** | ~500 kHz (heavy loads) |
| **No-load quiescent current** | 2–4 mA typical |
| **Sleep mode current** | ~10–20 µA per volt on VIN |
| **Dimensions** | 1″ × 1″ × 0.375″ (25.4 × 25.4 × 9.5 mm) |
| **Mounting holes** | Three 0.086″ holes for #2 or M2 screws |

## Features

- Input reverse voltage protection up to 40V
- Output undervoltage and overvoltage protection
- Over-current and short-circuit protection
- Thermal shutdown
- Soft-start feature (limits inrush current, gradually ramps output voltage)
- Power-save mode with ultrasonic operation (keeps switching frequency above 20 kHz)
- **Enable (EN) input** with precise cutoff threshold for low-power sleep state
- **"Power good" (PG) output** — goes low when output voltage is out of regulation

## Connections

| Pin | Function | Description |
|-----|---|---|
| **VIN** | Input voltage | 5.5V to 50V input power |
| **VRP** | Input after reverse protection | Access input voltage after reverse protection; can bypass protection |
| **VOUT** | Regulated output | 5V regulated output |
| **GND** | Ground | Common ground |
| **EN** | Enable | Active high (default enabled). Below 1.2V = sleep mode. |
| **PG** | Power Good | Open-drain output; low when output is out of regulation |

- All connections are on a 0.1″ grid for breadboard compatibility
- Power connections (VIN, VRP, VOUT, GND) are duplicated across both rows
- EN and PG are not duplicated — take care to avoid shorting when installing headers

> **Note:** Each header pin is rated for 3A (6A combined per pair). For higher-power applications, solder thick wires directly to the board.

## Dropout Voltage

The dropout voltage is the minimum amount by which the input voltage must exceed the output voltage. It increases approximately linearly with load. For 5V output, generally plan for VIN ≥ 6V under load.

## Power-Save Mode

- At light loads, reduces switching frequency to improve efficiency
- Keeps frequency above the audible range (20 kHz) — ultrasonic operation
- Under heavy load, the switcher operates in PWM mode regardless

## Thermal Considerations

> **Warning:** During normal operation, this product can get hot enough to burn you. Take care when handling.

Maximum continuous output current depends on:
- Input voltage
- Ambient temperature
- Air flow
- Heat sinking

## D36V50Fx Family

| Part # | Output Voltage |
|---|---|
| #4090 | 3.3V |
| **#4091** | **5V** |
| #4092 | 6V |
| #4093 | 7V |
| #4094 | 9V |
| #4095 | 12V |

## Included Hardware

- 1× D36V50F5 regulator board
- 1×12 (or 2×6) straight male header strips

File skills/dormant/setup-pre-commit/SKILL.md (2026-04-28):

---
name: setup-pre-commit
description: Set up Husky pre-commit hooks with lint-staged (Prettier), type checking, and tests in the current repo. Use when user wants to add pre-commit hooks, set up Husky, configure lint-staged, or add commit-time formatting/typechecking/testing.
---

# Setup Pre-Commit Hooks

## What This Sets Up

- **Husky** pre-commit hook
- **lint-staged** running Prettier on all staged files
- **Prettier** config (if missing)
- **typecheck** and **test** scripts in the pre-commit hook

## Steps

### 1. Detect package manager

Check for `package-lock.json` (npm), `pnpm-lock.yaml` (pnpm), `yarn.lock` (yarn), `bun.lockb` (bun). Use whichever is present. Default to npm if unclear.

### 2. Install dependencies

Install as devDependencies:

```
husky lint-staged prettier
```

### 3. Initialize Husky

```bash
npx husky init
```

This creates `.husky/` dir and adds `prepare: "husky"` to package.json.

### 4. Create `.husky/pre-commit`

Write this file (no shebang needed for Husky v9+):

```
npx lint-staged
npm run typecheck
npm run test
```

**Adapt**: Replace `npm` with detected package manager. If repo has no `typecheck` or `test` script in package.json, omit those lines and tell the user.

### 5. Create `.lintstagedrc`

```json
{
  "*": "prettier --ignore-unknown --write"
}
```

### 6. Create `.prettierrc` (if missing)

Only create if no Prettier config exists. Use these defaults:

```json
{
  "useTabs": false,
  "tabWidth": 2,
  "printWidth": 80,
  "singleQuote": false,
  "trailingComma": "es5",
  "semi": true,
  "arrowParens": "always"
}
```

### 7. Verify

- [ ] `.husky/pre-commit` exists and is executable
- [ ] `.lintstagedrc` exists
- [ ] `prepare` script in package.json is `"husky"`
- [ ] `prettier` config exists
- [ ] Run `npx lint-staged` to verify it works

### 8. Commit

Stage all changed/created files and commit with message: `Add pre-commit hooks (husky + lint-staged + prettier)`

This will run through the new pre-commit hooks — a good smoke test that everything works.

## Notes

- Husky v9+ doesn't need shebangs in hook files
- `prettier --ignore-unknown` skips files Prettier can't parse (images, etc.)
- The pre-commit runs lint-staged first (fast, staged-only), then full typecheck and tests

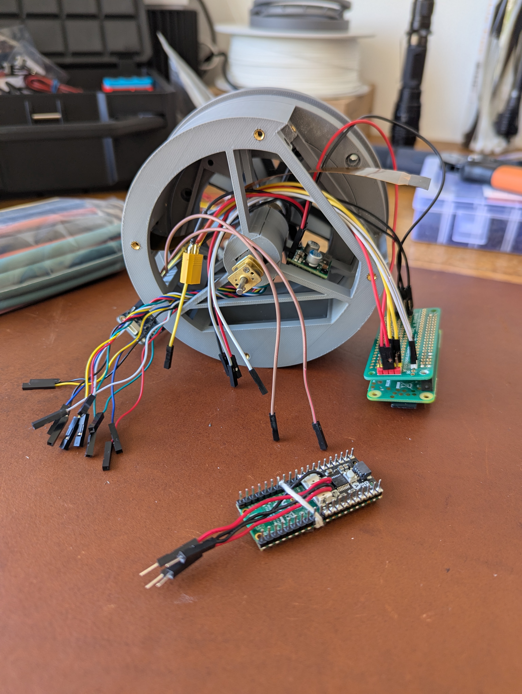
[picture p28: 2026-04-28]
images/stator_subassembly.jpg

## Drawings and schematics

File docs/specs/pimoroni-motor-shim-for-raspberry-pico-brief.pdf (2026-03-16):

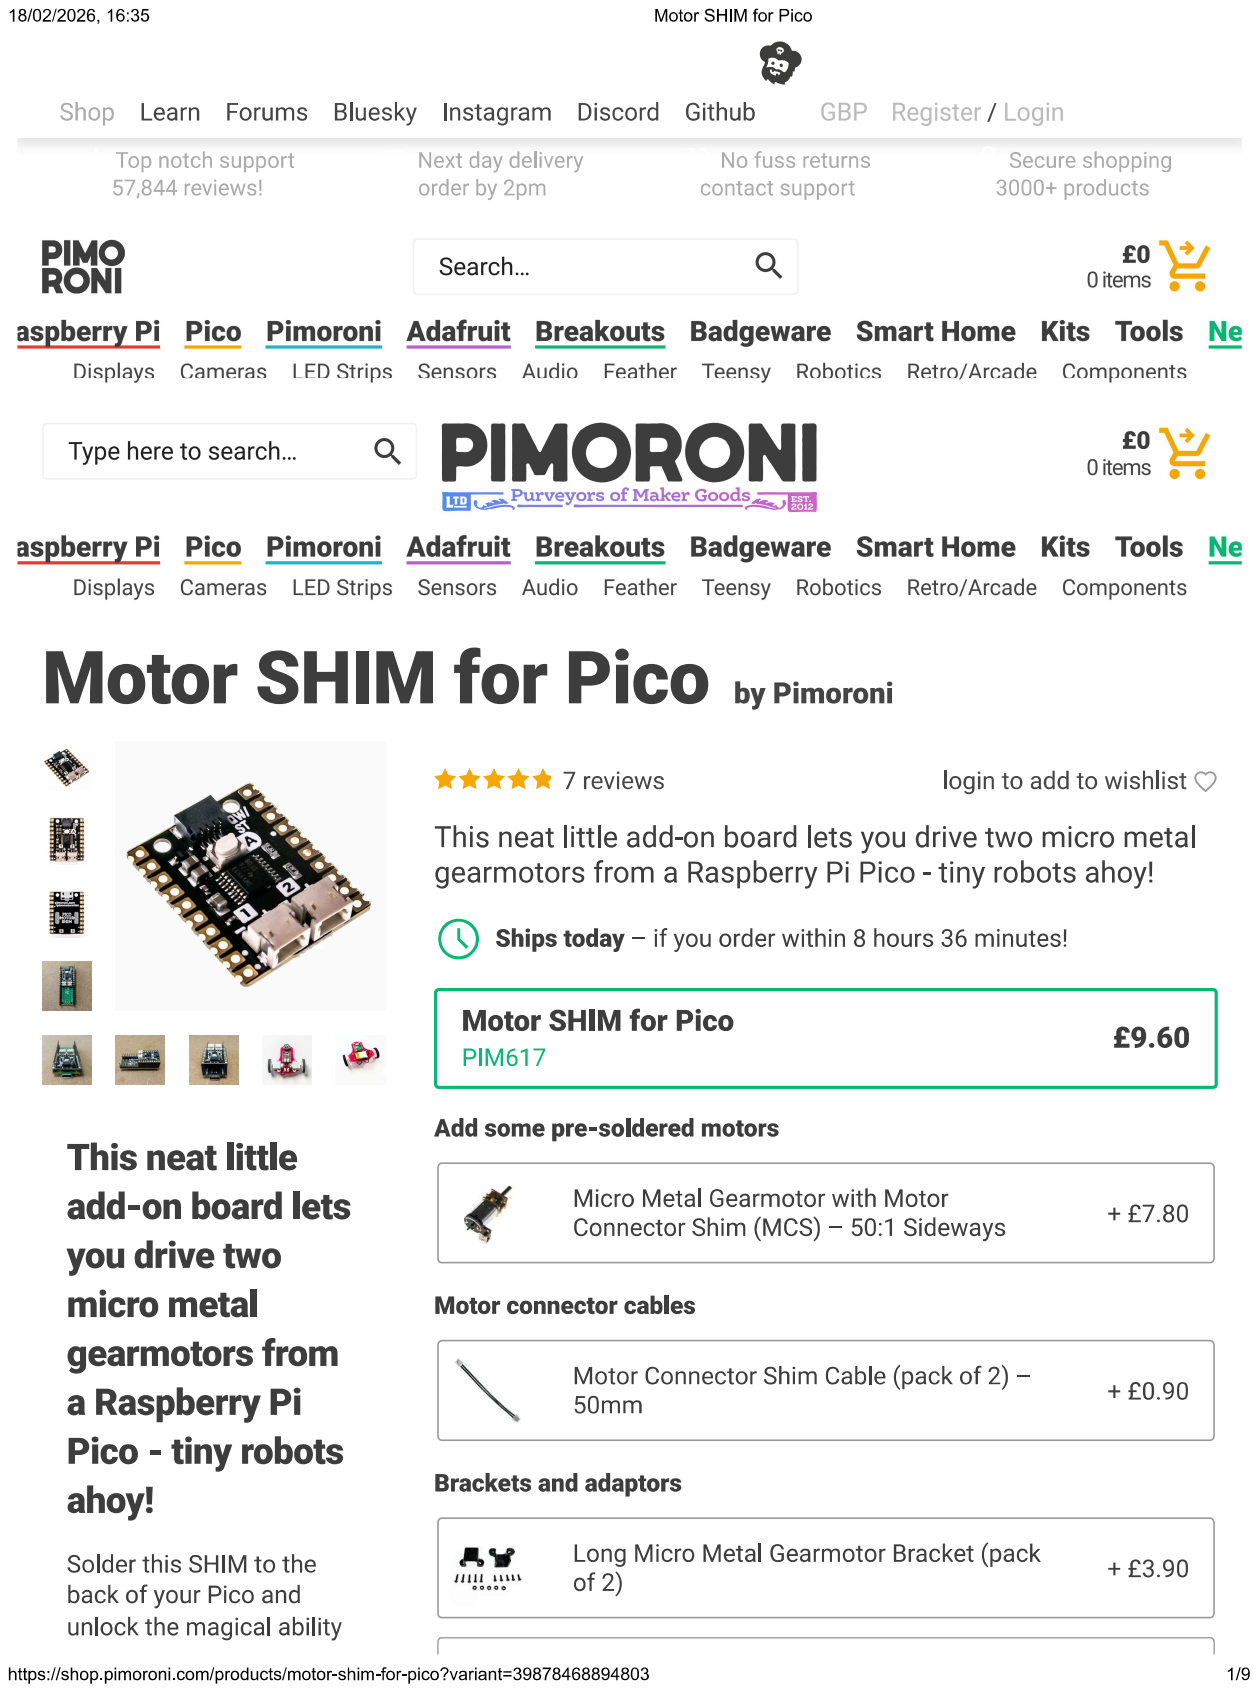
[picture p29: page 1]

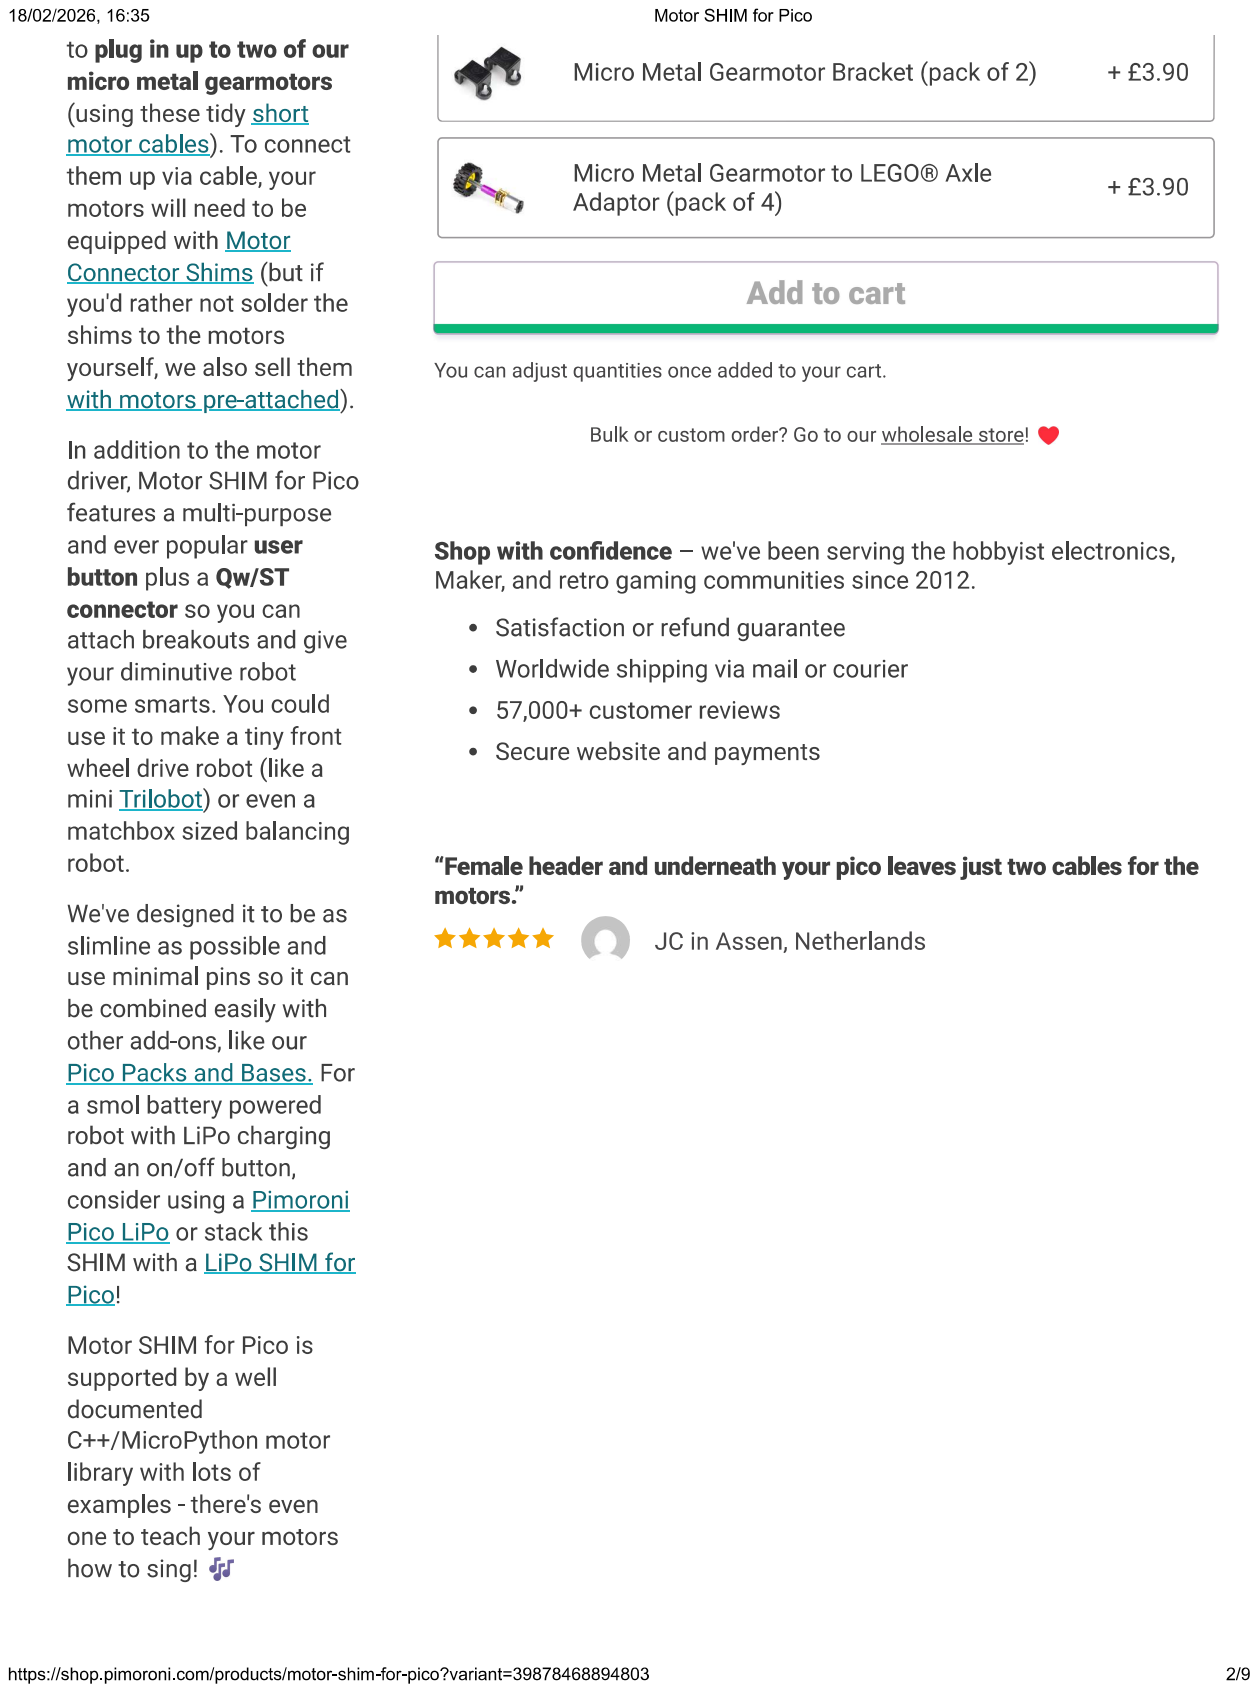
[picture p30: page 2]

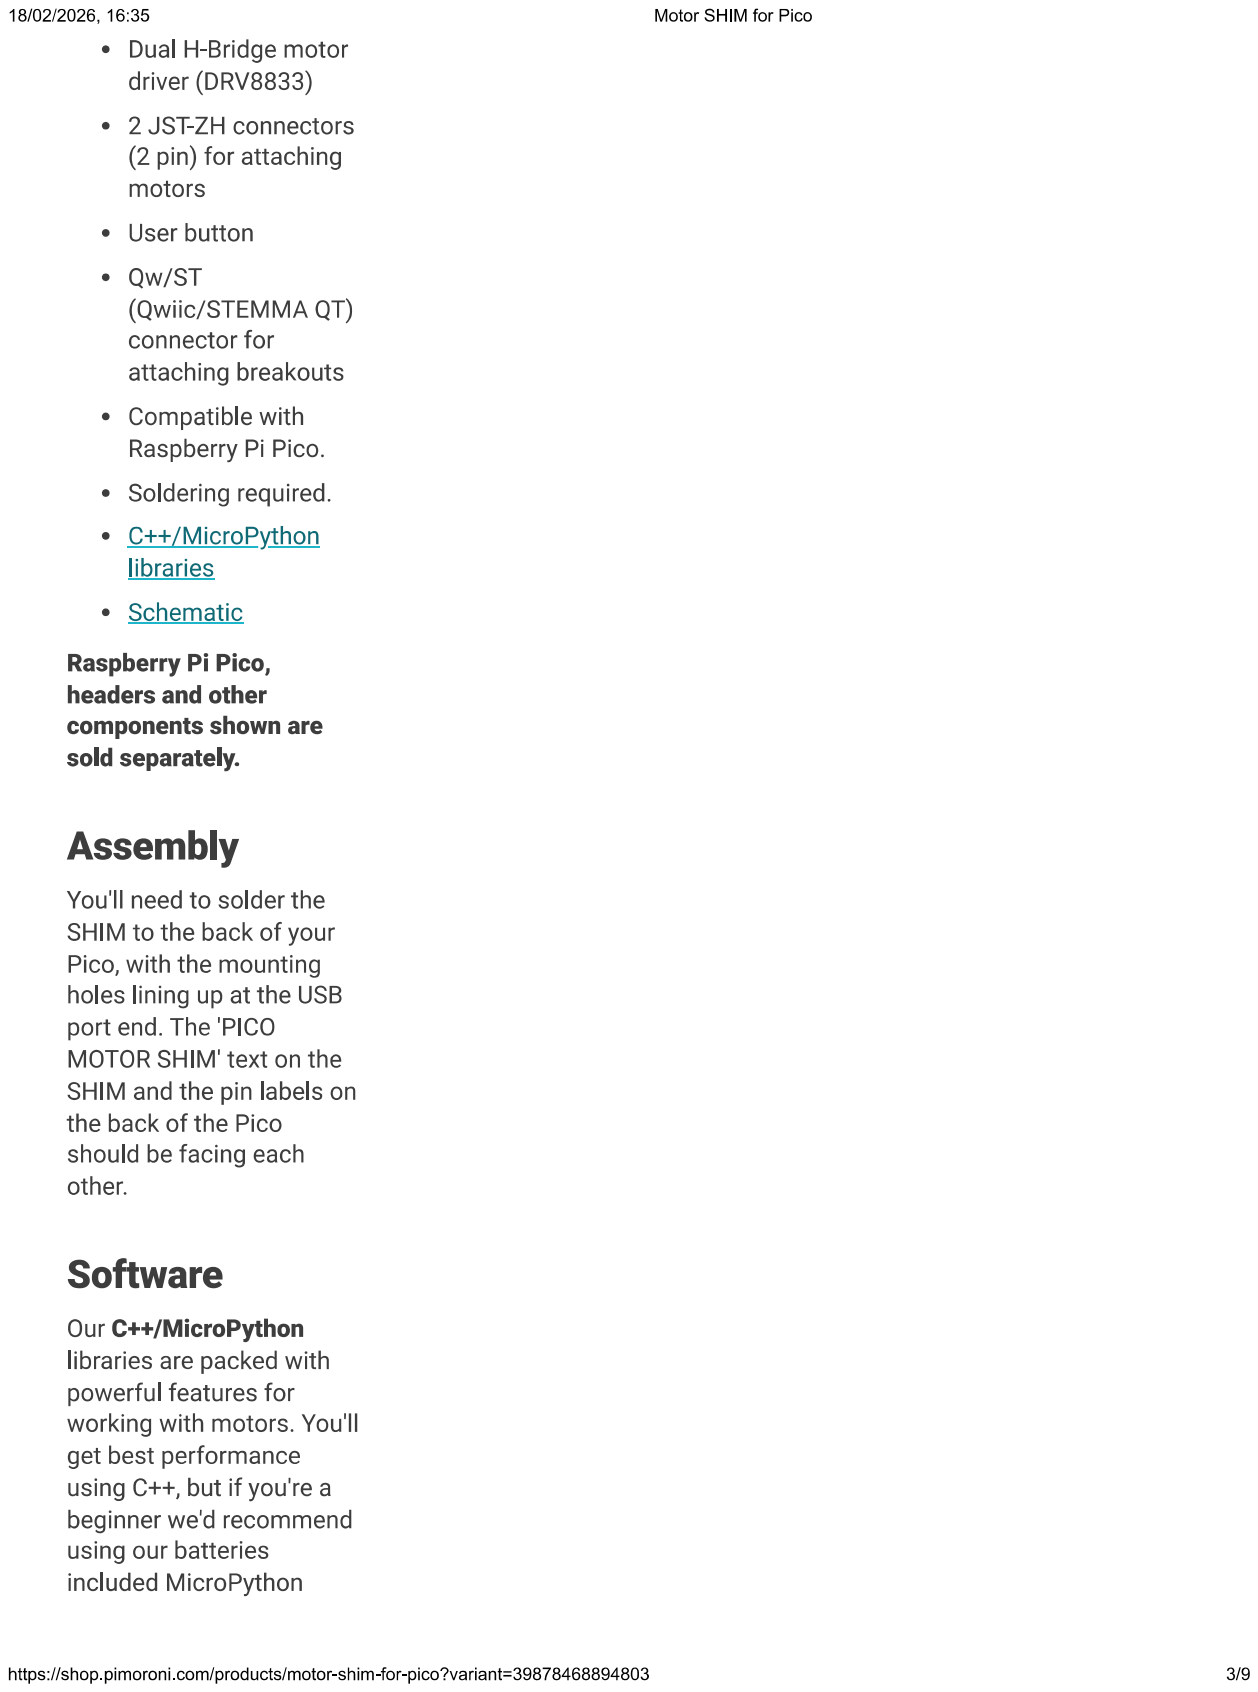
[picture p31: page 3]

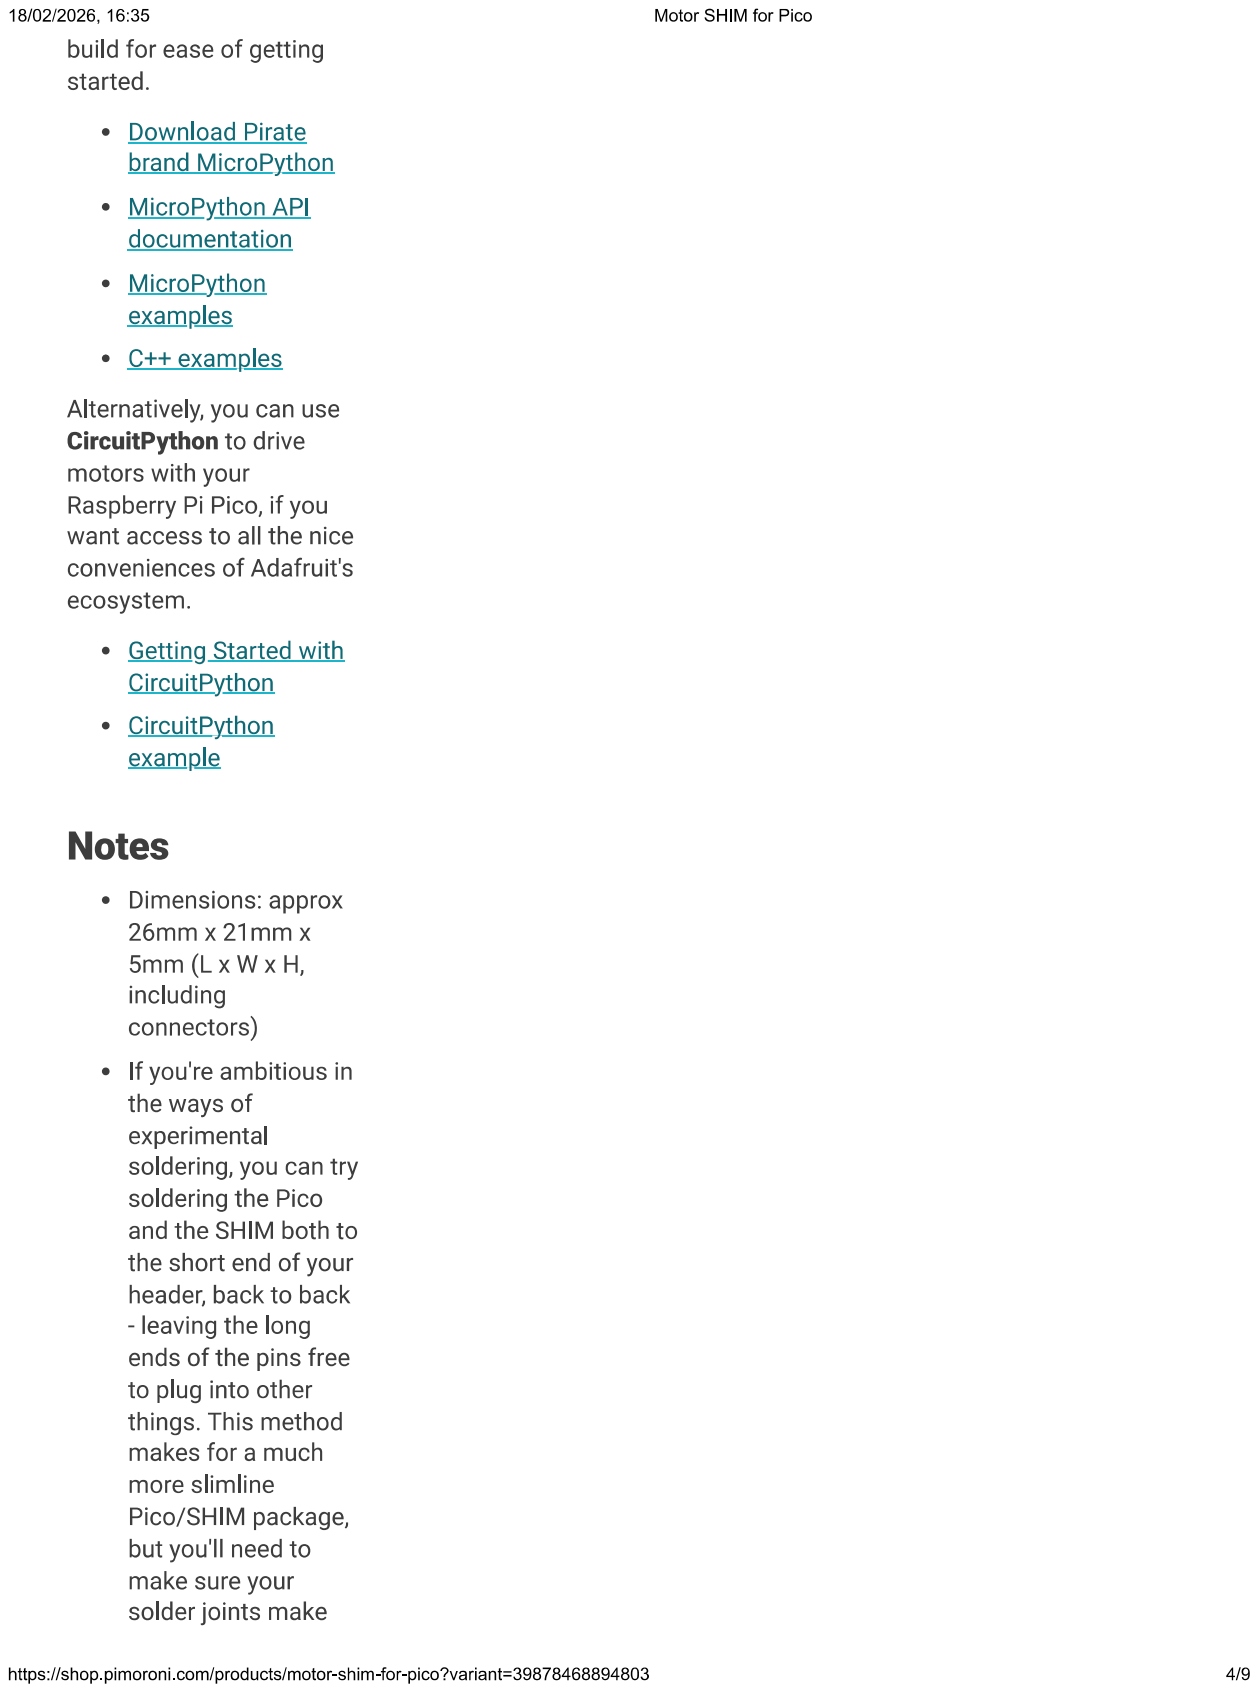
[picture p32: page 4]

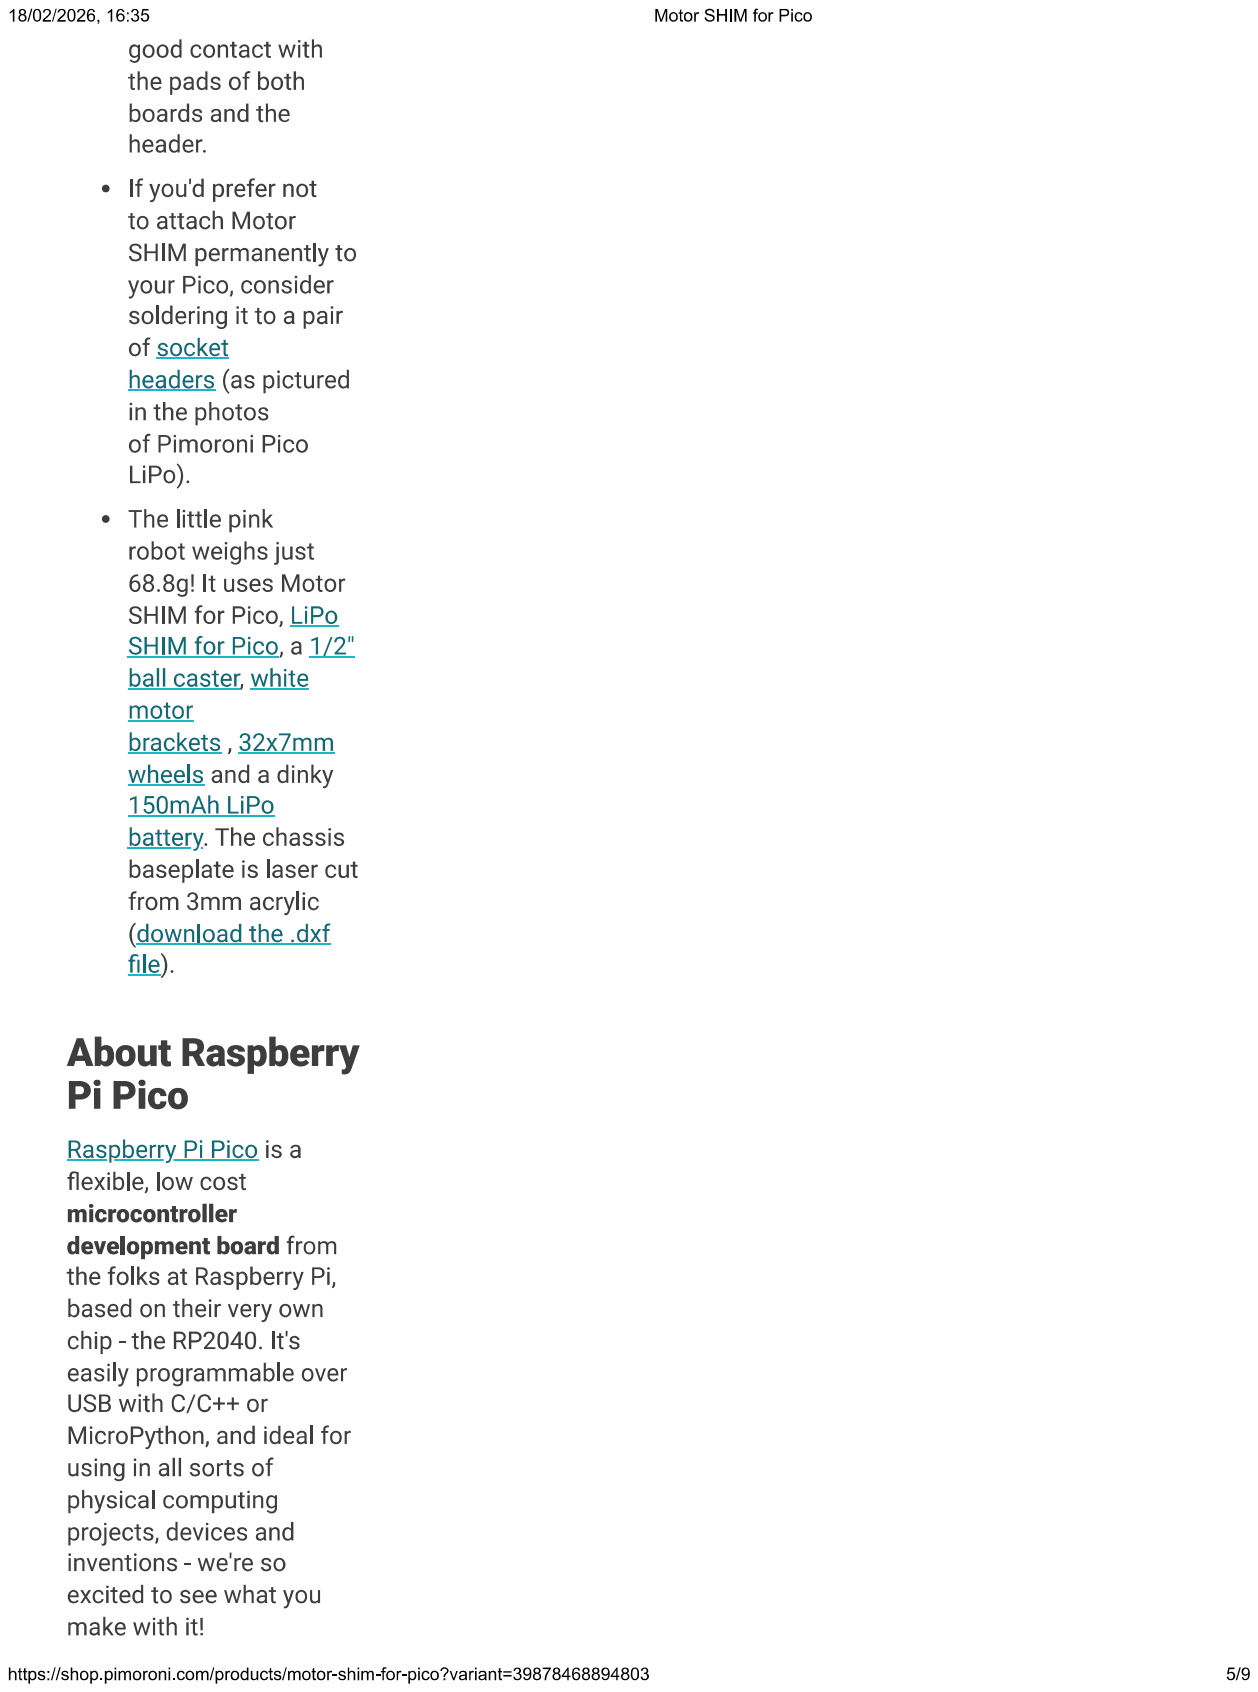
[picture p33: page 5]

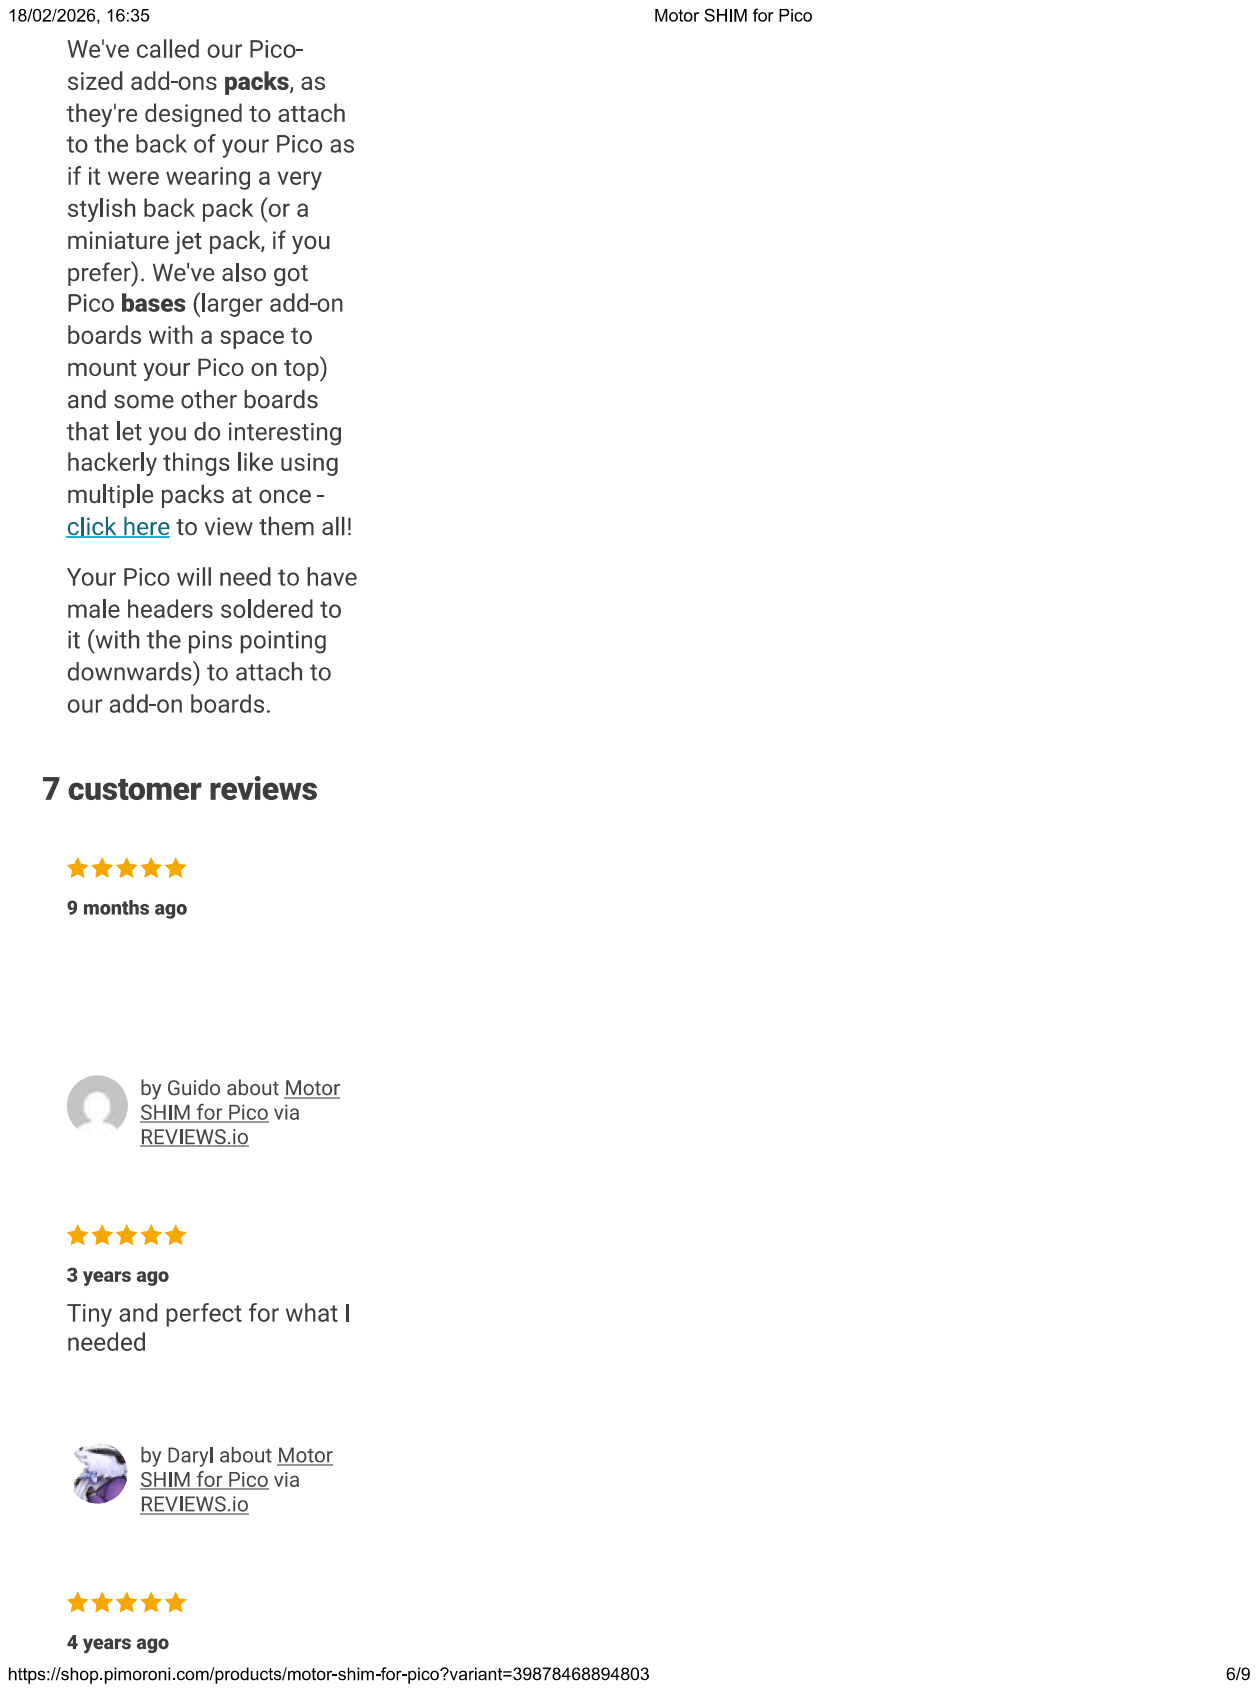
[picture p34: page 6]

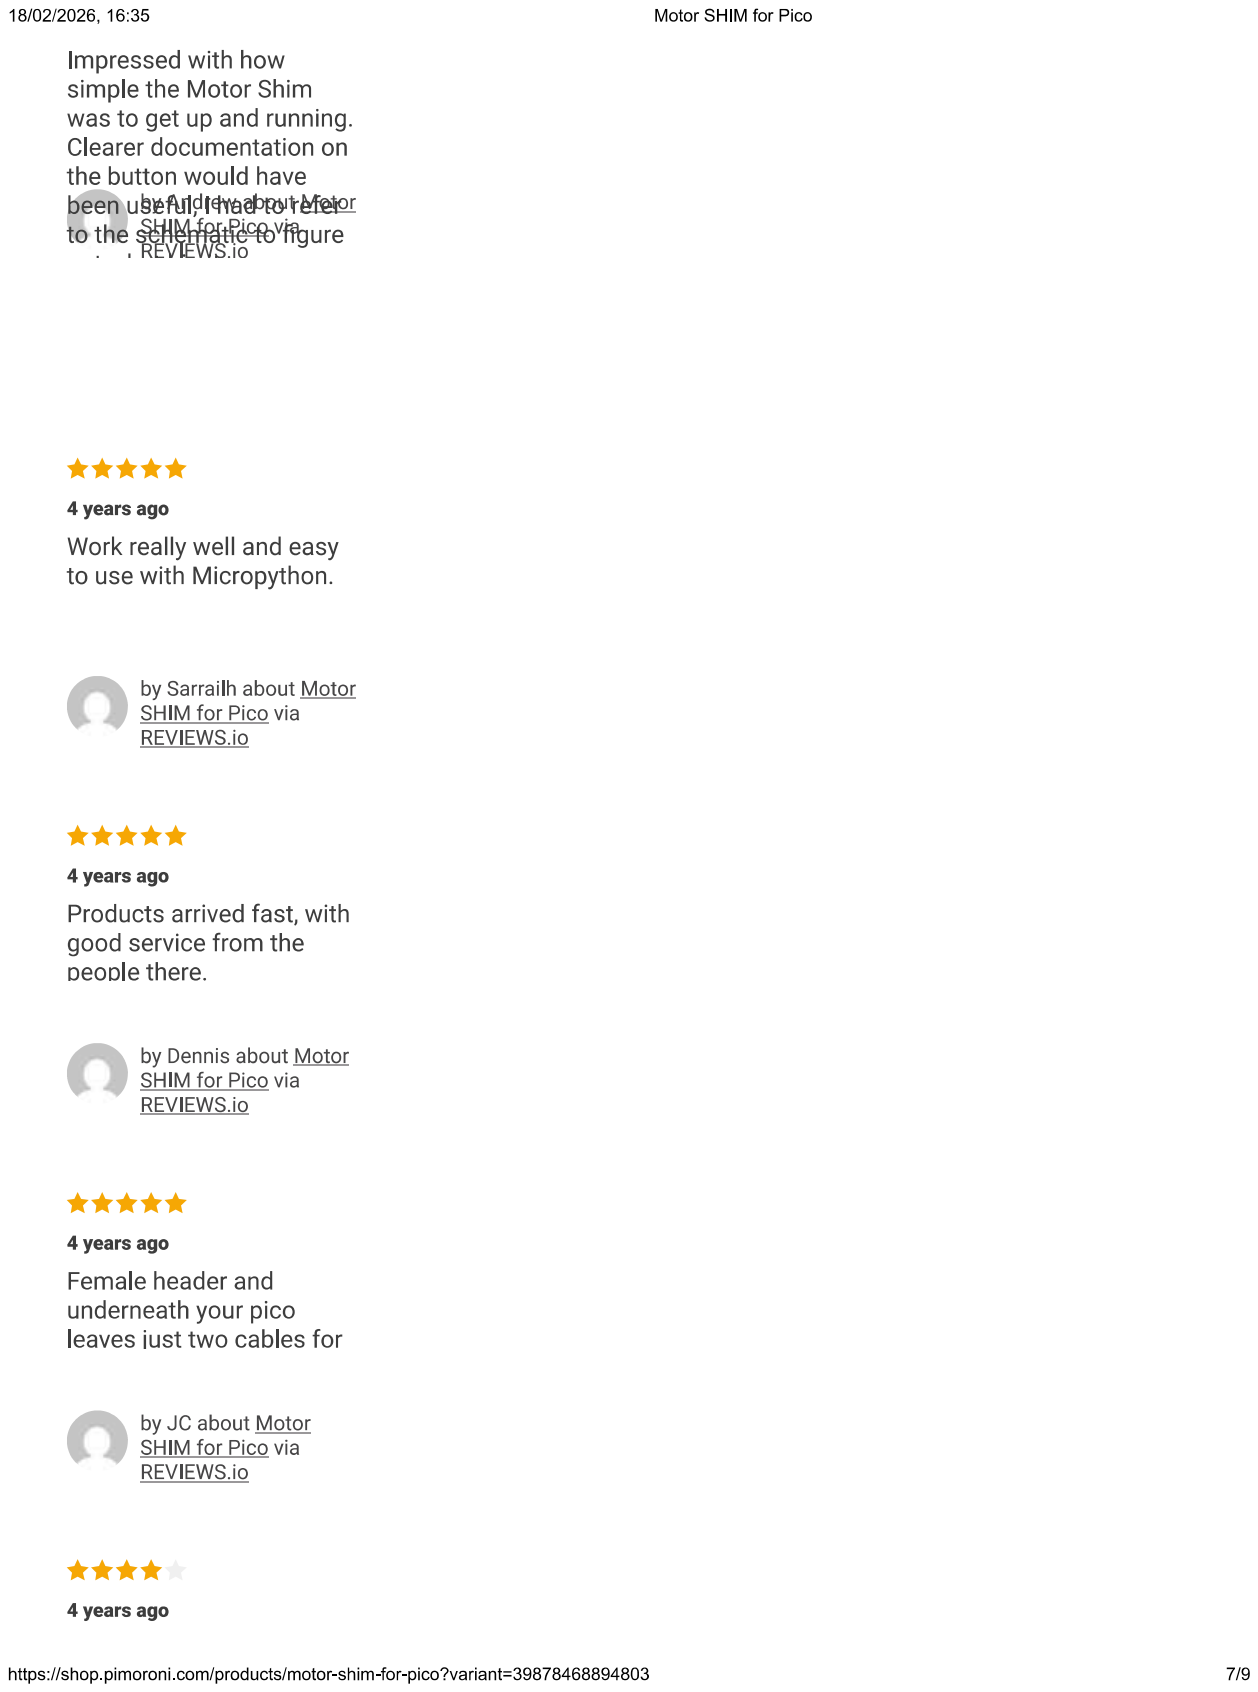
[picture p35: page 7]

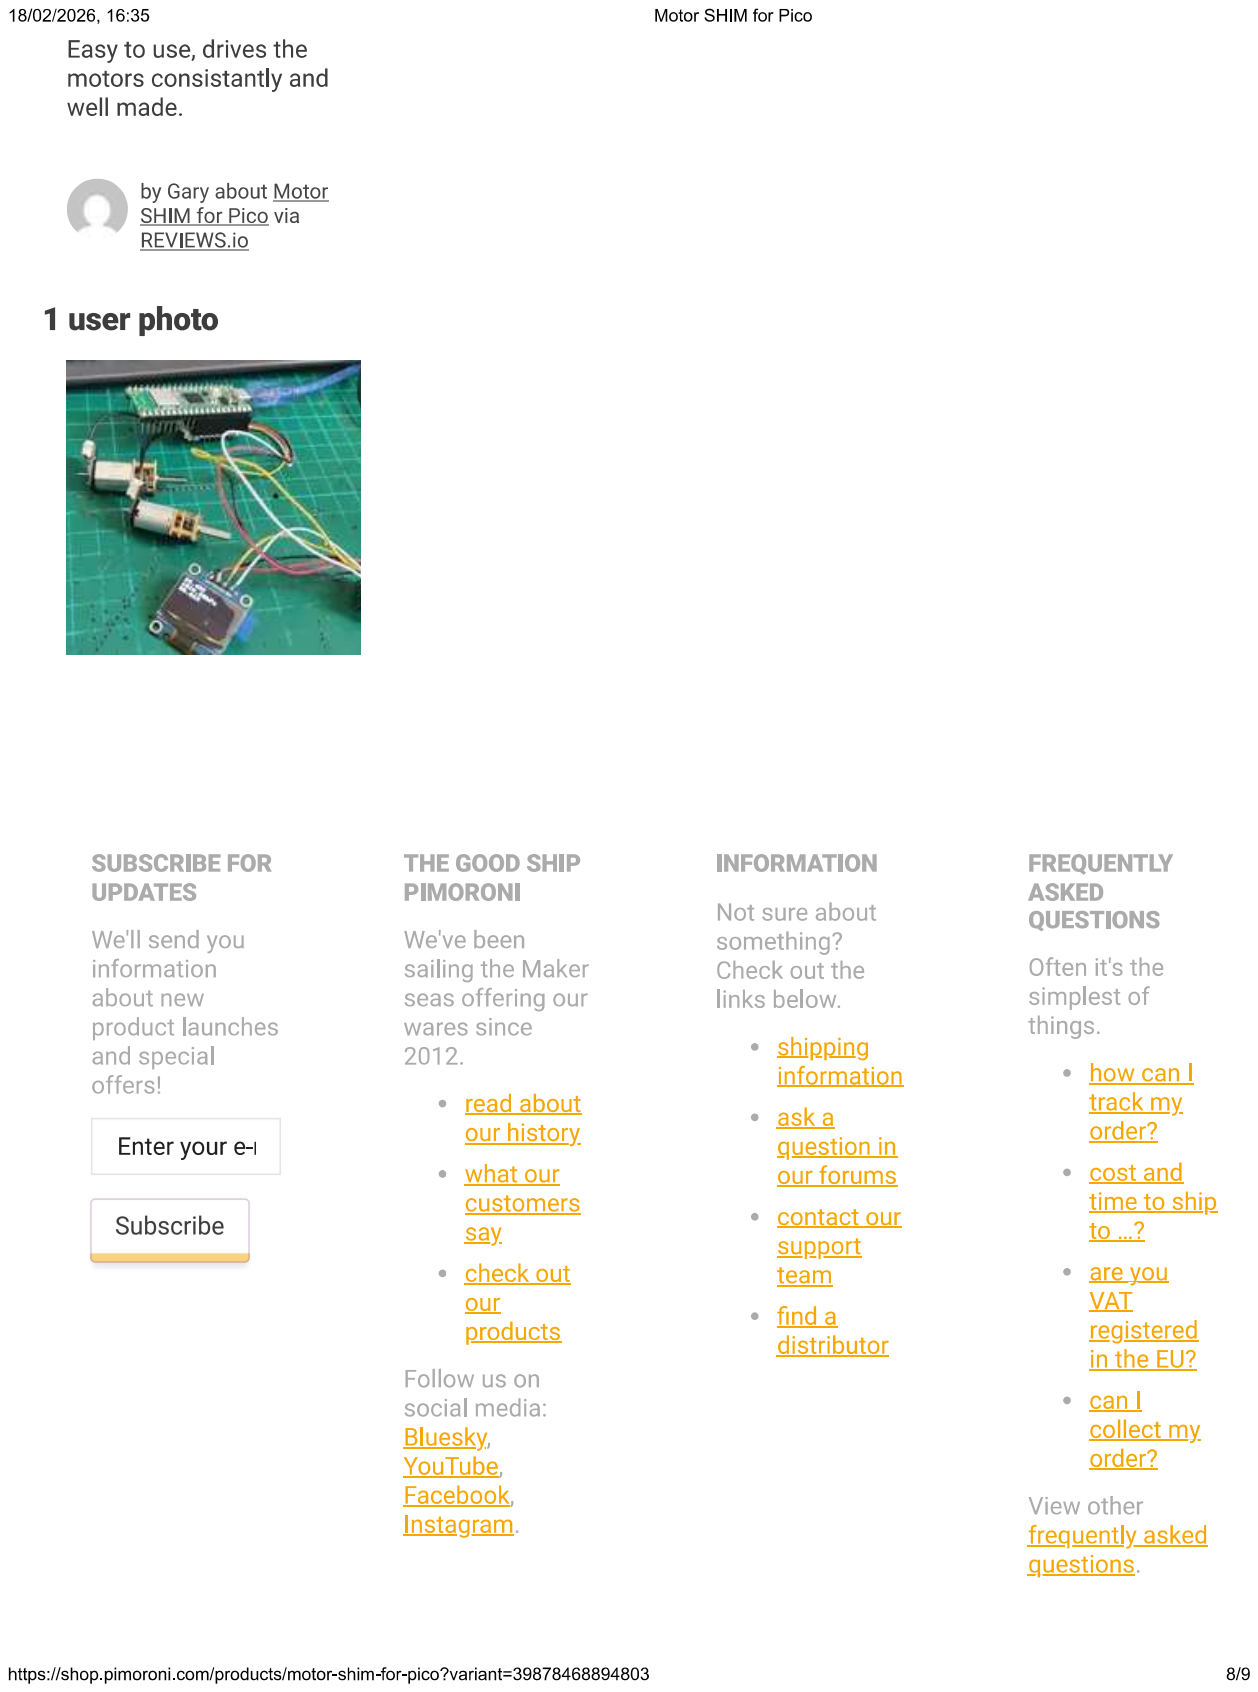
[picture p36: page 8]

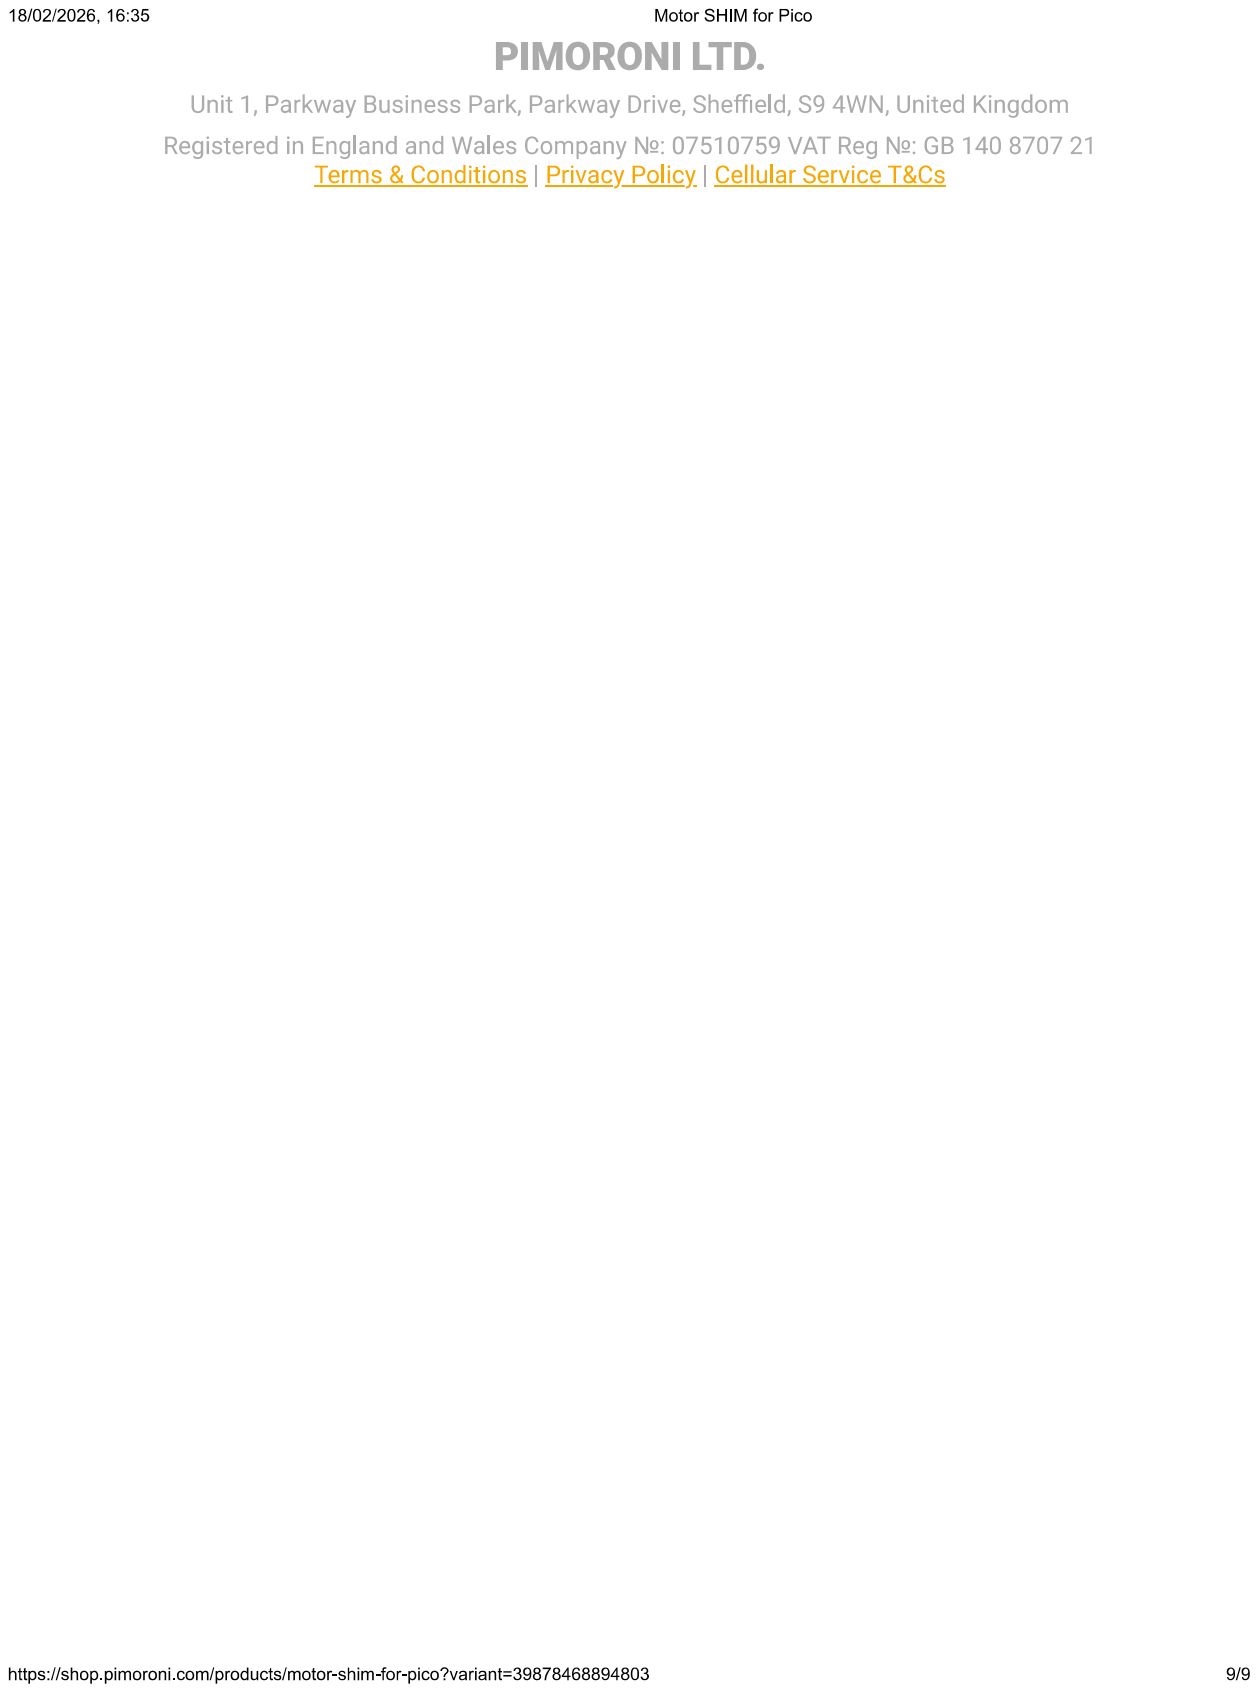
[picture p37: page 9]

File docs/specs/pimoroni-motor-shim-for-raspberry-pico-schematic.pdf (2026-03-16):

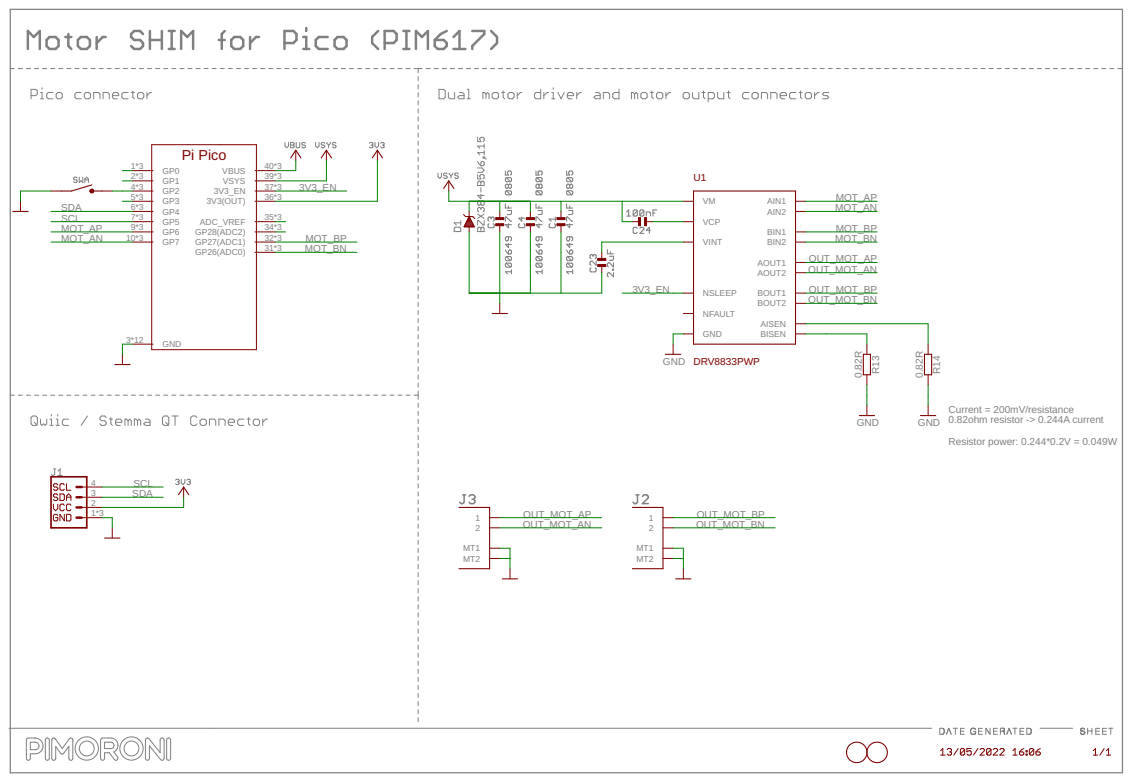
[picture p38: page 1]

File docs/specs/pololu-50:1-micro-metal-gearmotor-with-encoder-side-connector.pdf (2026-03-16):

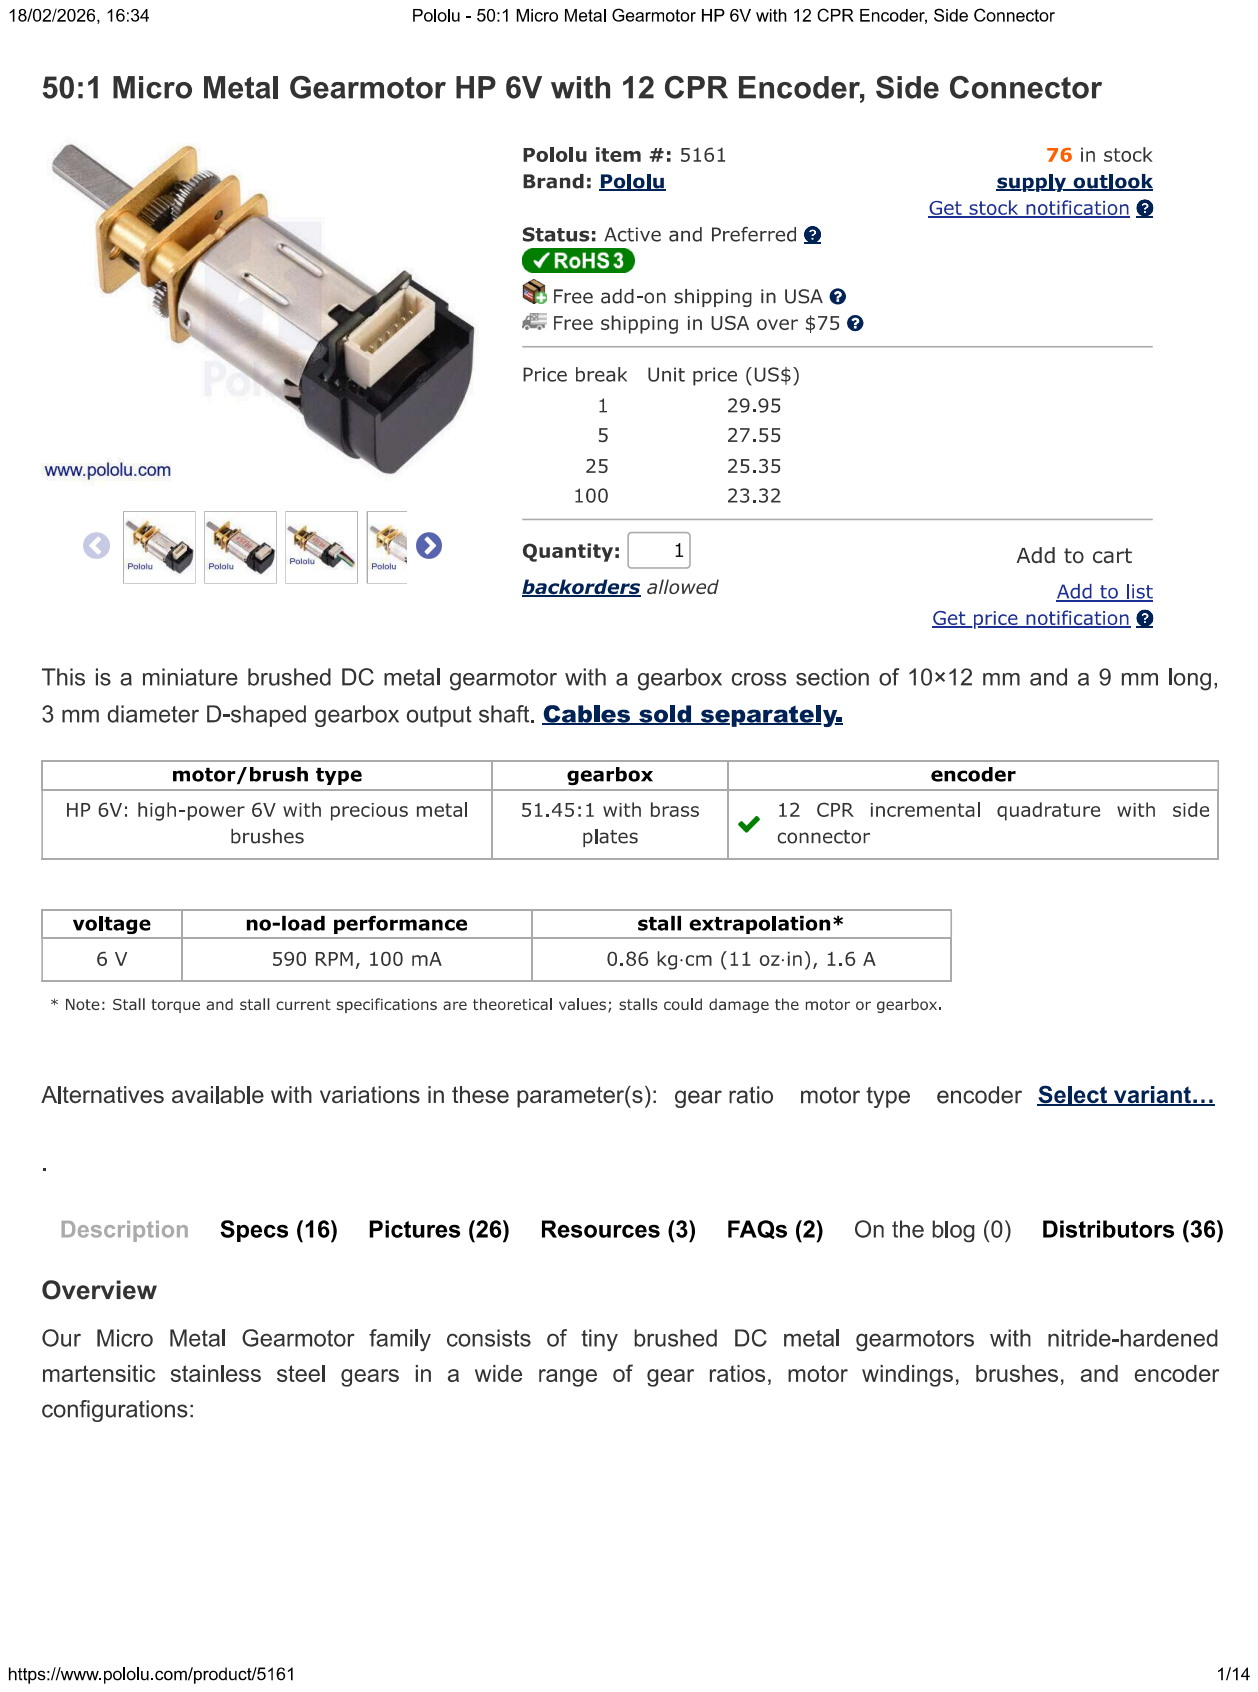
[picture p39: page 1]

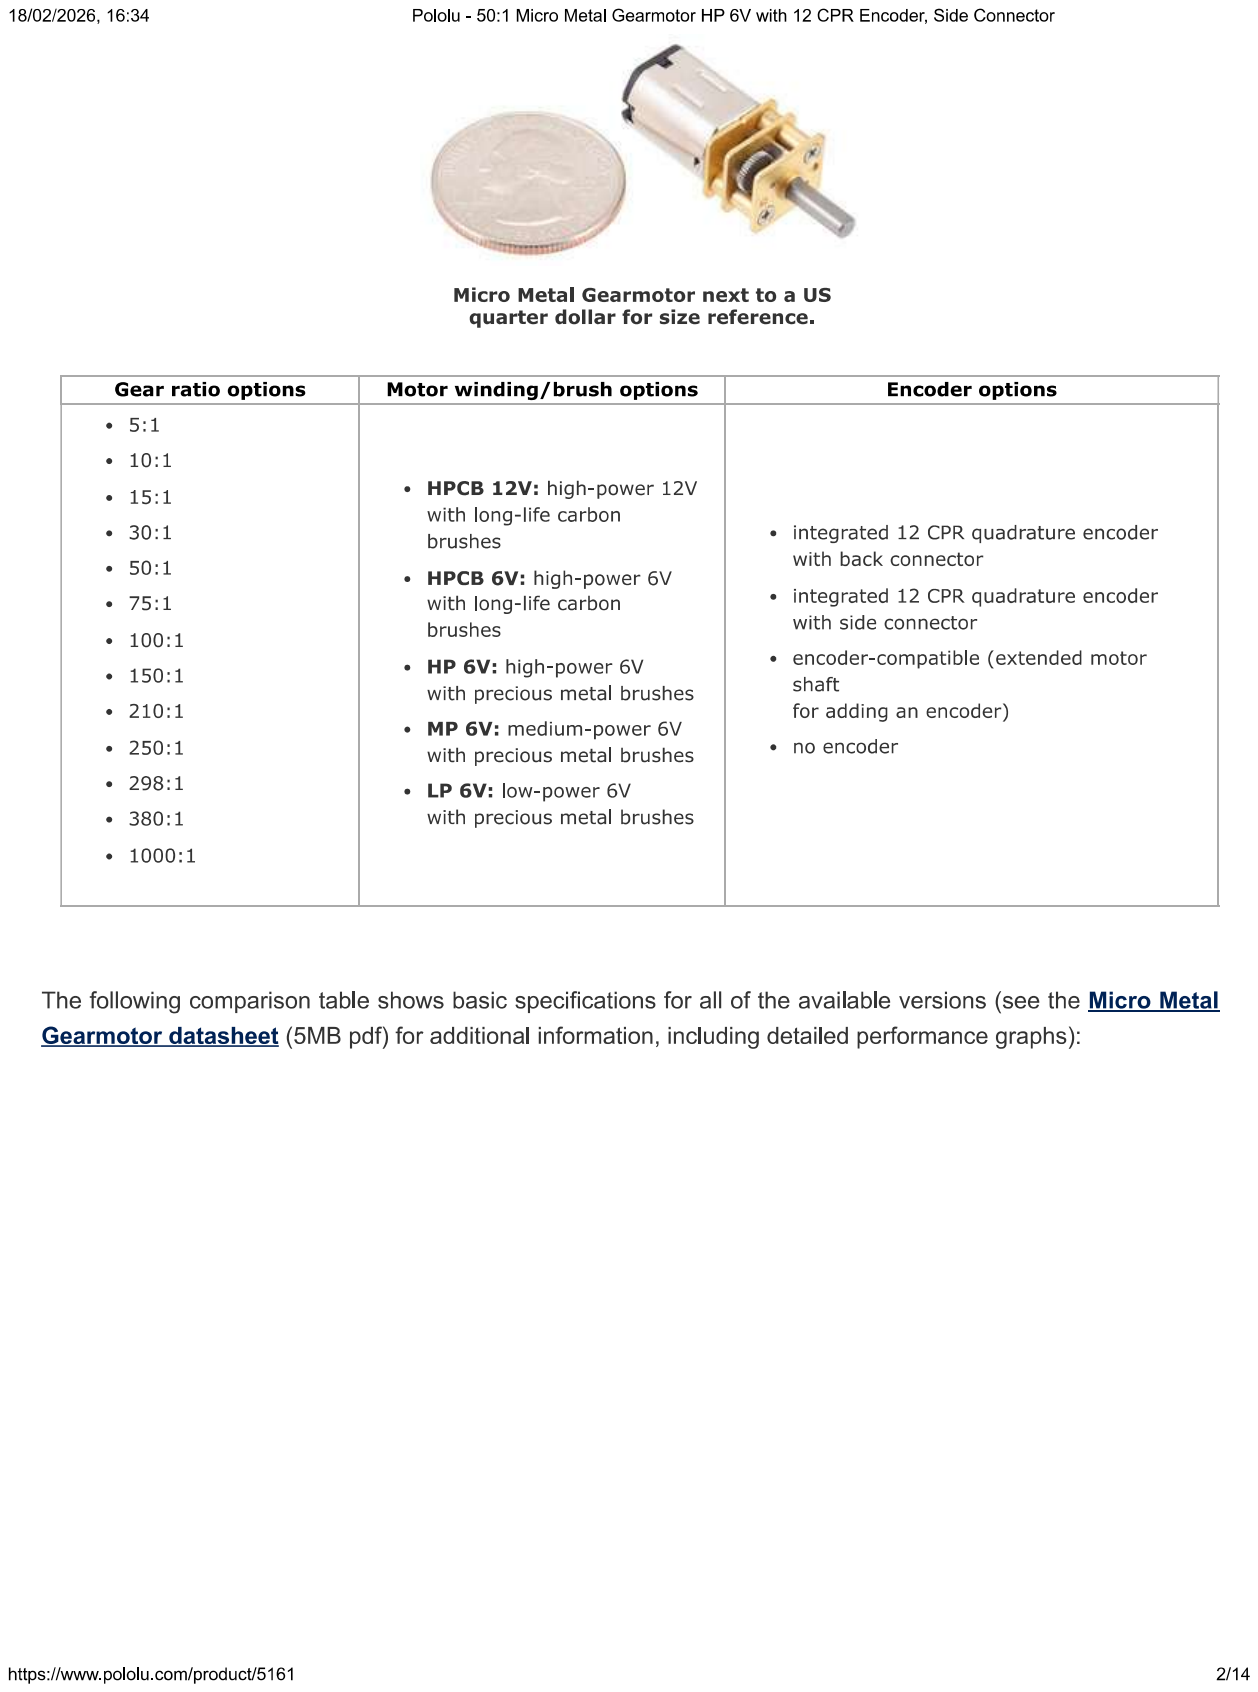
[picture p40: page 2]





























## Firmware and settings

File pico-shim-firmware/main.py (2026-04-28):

"""
Rollie Mk. I — Spherical Robot Angle Controller (main.py)
Runs on Raspberry Pi Pico 2 W with Pimoroni Motor SHIM + BNO055 IMU.
Uses standard MicroPython (no Pimoroni library — raw PWM for DRV8833).

The Pico acts as an Angle-Holding Coprocessor:
  - Reads pitch from BNO055 IMU (I2C, GP4/GP5 via SHIM STEMMA QT)
  - Runs a PID loop to hold the stator at a target pitch angle
  - Drives motors via DRV8833 on Motor SHIM (raw PWM)
  - Listens for <PITCH:xx>, <YAW:xx>, <STOP> commands on USB serial + UART

When target pitch = 0  -> ball stationary (camera level)
When target pitch = 10 -> ball rolls forward
When target pitch = -10 -> ball rolls backward
"""

import time
import sys
import select
from machine import Pin, PWM, I2C, UART

# Local BNO055 driver
from bno055_minimal import BNO055

# ============================================================================
# USER CONFIGURATION - TUNE THESE TO FIX MOTOR/ENCODER BEHAVIOR
# ============================================================================
# 1. MOTOR POLARITY: Put robot on stand. Press W. Both wheels MUST spin Forward.
INVERT_LEFT_MOTOR = False
INVERT_RIGHT_MOTOR = True

# 2. ENCODER POLARITY: When pushing the un-powered robot forward on desk,
#    the telemetry V: (Velocity) and E: (Encoder) MUST increase positively.
INVERT_LEFT_ENCODER = True
INVERT_RIGHT_ENCODER = True

# 3. BASELINE STATIC POWER (min_duty): 
#    If the motors jump too fast when starting, lower these numbers towards 0.
#    If the motors hum but don't move at low speeds, raise these numbers (max 65535).
#    If one motor is consistently slower/needs more power to start, adjust them independently!
MIN_DUTY_LEFT = 40000
MIN_DUTY_RIGHT = 40000

# 4. SPEED SCALING: Overall target speed limits (in ticks per second)
MAX_TICKS_PER_SEC = 500.0  # Top speed ceiling limit

# 5. VELOCITY TRACKING PID: If it stutters, lower P. If it's weak on carpet, raise I.
VEL_KP = 0.001  # Proportional correction
VEL_KI = 0.005  # Integral correction (pushes through friction)
VEL_KD = 0.0    # Derivative 
# ============================================================================

# Use Pi Zero Camera Feed's I2C timing configuration
I2C_FREQ = 400_000

# ============================================================================
# RAW DRV8833 MOTOR DRIVER (Pimoroni Motor SHIM pins)
# ============================================================================
# Motor SHIM schematic:
#   Motor A: AIN1 = GP6, AIN2 = GP7
#   Motor B: BIN1 = GP27, BIN2 = GP26
# DRV8833 truth table:
#   Forward:  IN1=PWM, IN2=LOW   -> OUT1=H, OUT2=L
#   Reverse:  IN1=LOW, IN2=PWM   -> OUT1=L, OUT2=H
#   Brake:    IN1=HIGH, IN2=HIGH -> OUT1=L, OUT2=L (slow decay / brake)
#   Coast:    IN1=LOW,  IN2=LOW  -> OUT1=Z, OUT2=Z

PWM_FREQ = 100  # 100 Hz — gives motors more torque/punch than 20kHz

class RawMotor:
    """Drive a DRV8833 H-bridge channel with raw PWM."""

    def __init__(self, pin1_num, pin2_num, min_duty=15000, invert=False):
        self.pwm1 = PWM(Pin(pin1_num))
        self.pwm2 = PWM(Pin(pin2_num))
        self.pwm1.freq(PWM_FREQ)
        self.pwm2.freq(PWM_FREQ)
        self.pwm1.duty_u16(0)
        self.pwm2.duty_u16(0)
        self.min_duty = min_duty
        self.invert = invert
        self.current_speed = 0.0
 
    def speed(self, spd):
        """Set speed from -1.0 (full reverse) to +1.0 (full forward)."""
        if self.invert:
            spd = -spd

        spd = max(-1.0, min(1.0, spd))
        abs_spd = abs(spd)
        
        self.current_speed = spd

        if abs_spd < 0.001:
            duty = 0
            self.current_speed = 0.0
        else:
            # Map [0.001, 1.0] to [min_duty, 65535] to smoothly overcome dynamic friction
            duty = int(self.min_duty + (65535 - self.min_duty) * abs_spd)
            
        if spd > 0:
            self.pwm1.duty_u16(duty)
            self.pwm2.duty_u16(0)
        elif spd < 0:
            self.pwm1.duty_u16(0)
            self.pwm2.duty_u16(duty)
        else:
            self.pwm1.duty_u16(0)
            self.pwm2.duty_u16(0)

    def brake(self):
        """Active brake (slow decay)."""
        self.pwm1.duty_u16(65535)
        self.pwm2.duty_u16(65535)

    def coast(self):
        """Coast (fast decay)."""
        self.pwm1.duty_u16(0)
        self.pwm2.duty_u16(0)

    def disable(self):
        """Disable PWM outputs."""
        self.pwm1.duty_u16(0)
        self.pwm2.duty_u16(0)


# ============================================================================
# HARDWARE SETUP
# ============================================================================

# Motors via DRV8833 on Motor SHIM
motor_left  = RawMotor(6, 7, min_duty=MIN_DUTY_LEFT, invert=INVERT_LEFT_MOTOR)     # Motor A: GP6 (AIN1), GP7 (AIN2)
motor_right = RawMotor(27, 26, min_duty=MIN_DUTY_RIGHT, invert=INVERT_RIGHT_MOTOR) # Motor B: GP27 (BIN1), GP26 (BIN2)

# BNO055 IMU via I2C1 (GP2 = SDA, GP3 = SCL) -> Moved to free up UART
i2c = I2C(1, sda=Pin(2), scl=Pin(3), freq=400_000)
imu = BNO055(i2c)

# UART0 for Pi Zero communication (GP0 = TX, GP1 = RX)
import os
try:
    os.dupterm(None, 1)
except:
    pass
uart = UART(0, baudrate=9600, tx=Pin(0), rx=Pin(1))

# Encoders (rising edge count on Channel A, direction on Channel B)
ENC_LEFT_A  = Pin(10, Pin.IN, Pin.PULL_UP)
ENC_LEFT_B  = Pin(11, Pin.IN, Pin.PULL_UP)
ENC_RIGHT_A = Pin(12, Pin.IN, Pin.PULL_UP)
ENC_RIGHT_B = Pin(13, Pin.IN, Pin.PULL_UP)

enc_left_count  = 0
enc_right_count = 0

def _enc_left_isr(pin):
    global enc_left_count
    if ENC_LEFT_B.value() ^ INVERT_LEFT_ENCODER:
        enc_left_count += 1
    else:
        enc_left_count -= 1

def _enc_right_isr(pin):
    global enc_right_count
    if ENC_RIGHT_B.value() ^ INVERT_RIGHT_ENCODER:
        enc_right_count += 1
    else:
        enc_right_count -= 1

ENC_LEFT_A.irq(trigger=Pin.IRQ_RISING, handler=_enc_left_isr)
ENC_RIGHT_A.irq(trigger=Pin.IRQ_RISING, handler=_enc_right_isr)

# Encoder constants
COUNTS_PER_REV = 617  # 12 CPR * 51.45:1 gear ratio

# ============================================================================
# PID CONTROLLER
# ============================================================================

class PID:
    """Simple PID controller with integral windup protection."""

    def __init__(self, kp, ki, kd, output_min=-1.0, output_max=1.0,
                 integral_limit=0.5):
        self.kp = kp
        self.ki = ki
        self.kd = kd
        self.output_min = output_min
        self.output_max = output_max
        self.integral_limit = integral_limit

        self._integral = 0.0
        self._prev_error = 0.0
        self._prev_time = time.ticks_ms()

    def update(self, error):
        """Calculate PID output given current error. Returns motor speed [-1, 1]."""
        now = time.ticks_ms()
        dt = time.ticks_diff(now, self._prev_time) / 1000.0  # seconds
        self._prev_time = now

        if dt <= 0 or dt > 0.5:
            self._prev_error = error
            return 0.0

        # Proportional
        p = self.kp * error

        # Integral with anti-windup
        self._integral += error * dt
        self._integral = max(-self.integral_limit,
                             min(self.integral_limit, self._integral))
        i = self.ki * self._integral

        # Derivative
        d = self.kd * (error - self._prev_error) / dt
        self._prev_error = error

        # Total output, clamped
        output = p + i + d
        return max(self.output_min, min(self.output_max, output))

    def reset(self):
        self._integral = 0.0
        self._prev_error = 0.0
        self._prev_time = time.ticks_ms()

# ============================================================================
# CONFIGURATION
# ============================================================================

# PID tuning — CONSERVATIVE starting values
PID_KP = 0.05
PID_KI = 0.005
PID_KD = 0.02

# Motor deadband — minimum speed to overcome shell friction
MOTOR_DEADBAND = 0.0

# Anti-tumble safety — hard angle limit (degrees)
ANTI_TUMBLE_ANGLE = 45.0

# Control loop frequency target
LOOP_FREQ_HZ = 100
LOOP_PERIOD_MS = 1000 // LOOP_FREQ_HZ  # 10ms

# Telemetry reporting interval
TELEMETRY_INTERVAL_MS = 200  # 5 Hz

# ============================================================================
# COMMAND PARSER
# ============================================================================

def parse_command(cmd_str):
    """
    Parse angle commands:
      <PITCH:xx>   — set target pitch
      <YAW:xx>     — set yaw offset
      <STOP>       — emergency stop
      <STATUS>     — request status report
      <DEADBAND:x> — set motor deadband
      <KP:x> <KI:x> <KD:x> — set PID gains
    """
    cmd_str = cmd_str.strip()
    if not cmd_str.startswith('<') or not cmd_str.endswith('>'):
        return None

    inner = cmd_str[1:-1]

    if inner == "STOP":
        return ("STOP", 0)
    if inner == "STATUS":
        return ("STATUS", 0)

    if ':' in inner:
        parts = inner.split(':', 1)
        try:
            return (parts[0].upper(), float(parts[1]))
        except ValueError:
            return None

    return None

# ============================================================================
# MAIN CONTROL LOOP
# ============================================================================

def apply_deadband(speed, deadband):
    if abs(speed) < 0.001:
        return 0.0
    if abs(speed) < deadband:
        return 0.0
    return speed

def emergency_stop():
    motor_left.speed(0)
    motor_right.speed(0)
    motor_left.disable()
    motor_right.disable()

def main():
    global MOTOR_DEADBAND, PID_KP, PID_KI, PID_KD

    print("[MAIN] Initializing BNO055 IMU...")
    imu_ok = False
    for attempt in range(5):
        try:
            if imu.begin():
                imu_ok = True
                break
        except Exception as e:
            print(f"[MAIN] IMU init attempt {attempt + 1}/5 error: {e}")
        time.sleep_ms(500)

    if not imu_ok:
        print("[MAIN] WARNING: BNO055 not found! Running in DIRECT DRIVE mode.")
        try:
            print("[MAIN] I2C scan:", [hex(a) for a in i2c.scan()])
        except:
            pass
        print("[MAIN] Motors will respond to PITCH as direct speed (no PID).")

    # Wait for initial calibration
    if imu_ok:
        print("[MAIN] Waiting for IMU calibration...")
        cal_start = time.ticks_ms()
        while time.ticks_diff(time.ticks_ms(), cal_start) < 5000:
            s, g, a, m = imu.calibration_status()
            print(f"[MAIN] Calibration: sys={s} gyro={g} accel={a} mag={m}")
            if g >= 2:
                print("[MAIN] Gyro calibrated — good enough to start!")
                break
            time.sleep_ms(500)

    # Create PID controller
    pid = PID(PID_KP, PID_KI, PID_KD)
    
    # Create Motor Velocity PID controllers (Low windup limit to prevent unstoppable runaways)
    left_pid = PID(VEL_KP, VEL_KI, VEL_KD, integral_limit=2.0)
    right_pid = PID(VEL_KP, VEL_KI, VEL_KD, integral_limit=2.0)

    # State
    target_pitch = 0.0
    yaw_offset = 0.0
    pid_active = True
    tumble_lockout = False

    # Serial input buffers
    usb_buf = ""
    uart_buf = ""

    # Polling for USB stdin
    poller = select.poll()
    poller.register(sys.stdin, select.POLLIN)

    last_telemetry = time.ticks_ms()
    prev_vel_time = time.ticks_ms()
    prev_left_enc = 0
    prev_right_enc = 0
    left_vel = 0.0
    right_vel = 0.0

    print("[MAIN] Control loop starting. Listening for commands...")
    print("[MAIN] Commands: <PITCH:x> <YAW:x> <STOP> <STATUS>")
    print("[MAIN] Tuning:   <KP:x> <KI:x> <KD:x> <DEADBAND:x>")

    while True:
        loop_start = time.ticks_ms()

        # ---- CALCULATE VELOCITY ----
        now_vel = time.ticks_ms()
        dt_vel_ms = time.ticks_diff(now_vel, prev_vel_time)
        if dt_vel_ms >= 50:  # Compute every ~50ms for smoother counts
            dt_vel_s = dt_vel_ms / 1000.0
            curr_left_enc = enc_left_count
            curr_right_enc = enc_right_count
            
            raw_left_vel = (curr_left_enc - prev_left_enc) / dt_vel_s
            raw_right_vel = (curr_right_enc - prev_right_enc) / dt_vel_s
            
            # Simple EMA filter to smooth discrete tick noise
            left_vel = (0.5 * raw_left_vel) + (0.5 * left_vel)
            right_vel = (0.5 * raw_right_vel) + (0.5 * right_vel)
            
            prev_left_enc = curr_left_enc
            prev_right_enc = curr_right_enc
            prev_vel_time = now_vel

        # ---- READ IMU ----
        current_pitch = 0.0
        gyro_data = (0.0, 0.0, 0.0)
        if imu_ok:
            try:
                current_pitch = imu.pitch()
                gyro_data = imu.gyro()
            except Exception:
                pass

        # ---- ANTI-TUMBLE CHECK ----
        if abs(current_pitch) > ANTI_TUMBLE_ANGLE and imu_ok:
            if not tumble_lockout:
                print(f"[SAFETY] ANTI-TUMBLE! Pitch {current_pitch:.1f}deg BRAKING!")
                tumble_lockout = True
            brake_dir = -1.0 if current_pitch > 0 else 1.0
            motor_left.speed(brake_dir * 0.3)
            motor_right.speed(brake_dir * 0.3)
        else:
            if tumble_lockout:
                print("[SAFETY] Pitch back in safe zone. Resuming PID.")
                tumble_lockout = False
                pid.reset()

            # ---- PID LOOP (IMU available) ----
            if pid_active and imu_ok:
                error = target_pitch - current_pitch
                pid_output = pid.update(error)

                # Map pitch PID to normalized target velocity
                base_speed = pid_output
                left_target = (base_speed + yaw_offset) * MAX_TICKS_PER_SEC
                right_target = (base_speed - yaw_offset) * MAX_TICKS_PER_SEC

                if abs(left_target) < 1.0:
                    left_power = 0.0
                    left_pid.reset()
                else:
                    left_ff = left_target / MAX_TICKS_PER_SEC
                    left_power = left_ff + left_pid.update(left_target - left_vel)
                
                if abs(right_target) < 1.0:
                    right_power = 0.0
                    right_pid.reset()
                else:
                    right_ff = right_target / MAX_TICKS_PER_SEC
                    right_power = right_ff + right_pid.update(right_target - right_vel)

                motor_left.speed(left_power)
                motor_right.speed(right_power)

            # ---- DIRECT DRIVE (no IMU) ----
            elif not imu_ok:
                # Map pitch directly to normalized velocity target: pitch/30 = target_speed_norm
                base_speed = target_pitch / 30.0
                base_speed = max(-1.0, min(1.0, base_speed))

                left_target = (base_speed + yaw_offset) * MAX_TICKS_PER_SEC
                right_target = (base_speed - yaw_offset) * MAX_TICKS_PER_SEC

                if abs(left_target) < 1.0:
                    left_power = 0.0
                    left_pid.reset()
                else:
                    left_ff = left_target / MAX_TICKS_PER_SEC
                    left_power = left_ff + left_pid.update(left_target - left_vel)
                
                if abs(right_target) < 1.0:
                    right_power = 0.0
                    right_pid.reset()
                else:
                    right_ff = right_target / MAX_TICKS_PER_SEC
                    right_power = right_ff + right_pid.update(right_target - right_vel)

                motor_left.speed(left_power)
                motor_right.speed(right_power)

        # ---- READ COMMANDS FROM USB (stdin) ----
        if poller.poll(0):
            ch = sys.stdin.read(1)
            if ch == '\n' or ch == '\r':
                if usb_buf:
                    result = parse_command(usb_buf)
                    if result:
                        cmd_type, cmd_val = result
                        if cmd_type == "PITCH":
                            target_pitch = cmd_val
                            pid.reset()
                            print(f"[CMD] Target pitch: {target_pitch:.1f}deg")
                        elif cmd_type == "YAW":
                            yaw_offset = cmd_val / 100.0
                            print(f"[CMD] Yaw offset: {yaw_offset:.3f}")
                        elif cmd_type == "STOP":
                            target_pitch = 0.0
                            yaw_offset = 0.0
                            pid.reset()
                            left_pid.reset()
                            right_pid.reset()
                            emergency_stop()
                            print("[CMD] EMERGENCY STOP")
                        elif cmd_type == "STATUS":
                            s, g, a, m = imu.calibration_status() if imu_ok else (0,0,0,0)
                            print(f"[STATUS] Pitch:{current_pitch:.1f} Target:{target_pitch:.1f} Yaw:{yaw_offset:.3f}")
                            print(f"[STATUS] Cal:s={s} g={g} a={a} m={m}")
                            print(f"[STATUS] Enc:L={enc_left_count} R={enc_right_count}")
                            print(f"[STATUS] PID:kp={PID_KP} ki={PID_KI} kd={PID_KD} db={MOTOR_DEADBAND}")
                        elif cmd_type == "DEADBAND":
                            MOTOR_DEADBAND = cmd_val
                            print(f"[CMD] Deadband: {MOTOR_DEADBAND}")
                        elif cmd_type == "KP":
                            PID_KP = cmd_val; pid.kp = cmd_val
                            print(f"[CMD] KP: {PID_KP}")
                        elif cmd_type == "KI":
                            PID_KI = cmd_val; pid.ki = cmd_val
                            print(f"[CMD] KI: {PID_KI}")
                        elif cmd_type == "KD":
                            PID_KD = cmd_val; pid.kd = cmd_val
                            print(f"[CMD] KD: {PID_KD}")
                    usb_buf = ""
            else:
                usb_buf += ch

        # ---- READ COMMANDS FROM UART (Pi Zero) ----
        if uart.any():
            data = uart.read()
            if data:
                uart_buf += data.decode('utf-8', 'ignore')
                while '\n' in uart_buf:
                    line, uart_buf = uart_buf.split('\n', 1)
                    line = line.strip()
                    uart.write(f"[UART-RX] {line}\n".encode('utf-8'))
                    result = parse_command(line)
                    if result:
                        cmd_type, cmd_val = result
                        if cmd_type == "PITCH":
                            target_pitch = cmd_val
                            pid.reset()
                        elif cmd_type == "YAW":
                            yaw_offset = cmd_val / 100.0
                        elif cmd_type == "STOP":
                            target_pitch = 0.0
                            yaw_offset = 0.0
                            pid.reset()
                            left_pid.reset()
                            right_pid.reset()
                            emergency_stop()

        # ---- TELEMETRY ----
        now = time.ticks_ms()
        if time.ticks_diff(now, last_telemetry) >= TELEMETRY_INTERVAL_MS:
            last_telemetry = now
            cal = imu.calibration_status() if imu_ok else (0,0,0,0)
            telemetry_str = (f"P:{current_pitch:+6.1f} T:{target_pitch:+6.1f} "
                             f"G:{gyro_data[1]:+6.1f} "
                             f"C:{cal[0]}{cal[1]}{cal[2]}{cal[3]} "
                             f"E:{enc_left_count}/{enc_right_count} V:{left_vel:.0f}/{right_vel:.0f}")
            print(telemetry_str)
            uart.write(b'[PICO_HEARTBEAT] I ALIVE!\n')
            uart.write((telemetry_str + "\n").encode('utf-8'))

        # ---- LOOP TIMING ----
        elapsed = time.ticks_diff(time.ticks_ms(), loop_start)
        if elapsed < LOOP_PERIOD_MS:
            time.sleep_ms(LOOP_PERIOD_MS - elapsed)


# ============================================================================
# ENTRY POINT
# ============================================================================
if __name__ == "__main__":
    time.sleep(1)
    try:
        main()
    except KeyboardInterrupt:
        emergency_stop()
        print("[MAIN] Interrupted. Motors stopped.")
    except Exception as e:
        emergency_stop()
        print(f"[MAIN] FATAL: {e}")
        import sys as _sys
        _sys.print_exception(e)

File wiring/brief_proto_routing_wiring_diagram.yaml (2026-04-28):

metadata:
  title: Rollie Mk. I - Brief Wiring (Proto Signal Routing)
  description: Self-balancing spherical robot - signals routed via protoboard, UART direct
  notes: "I2C and encoders via protoboard (pull-ups, replaceability). UART and motor power direct."

connectors:
  Batt:
    type: GNB 7.4V 2S LiPo
    subtype: XT30
    pinlabels: [V+, V-]
    notes: Battery

  Reg:
    type: Pololu D24V30F5
    subtype: Step-Down 5V 3.2A
    pinlabels: [VIN, GND, VOUT 5V]
    notes: "POLOLU-3782"

  PB:
    type: ProtoBoard 58x78mm
    subtype: FIT0203
    pinlabels:
      - V+ In (7.4V)   # 1
      - GND Rail       # 2
      - 5V Rail (Reg)  # 3
      - 3V3 Rail       # 4
      - I2C SDA        # 5
      - I2C SCL        # 6
      - Left Enc A     # 7
      - Left Enc B     # 8
      - Right Enc A    # 9
      - Right Enc B    # 10
    notes: "Power rails + I2C/encoder pads. 4.7k pull-ups on SDA/SCL to 3V3."

  P:
    type: Raspberry Pi Pico H
    pinlabels:
      - VSYS 5V        # 1
      - GND            # 2
      - 3V3 OUT        # 3
      - GP0 TX         # 4
      - GP1 RX         # 5
      - GP4 SDA        # 6
      - GP5 SCL        # 7
      - GP10 Enc LA    # 8
      - GP11 Enc LB    # 9
      - GP12 Enc RA    # 10
      - GP13 Enc RB    # 11
    notes: "CE08702 - Reflexes (500Hz balance loop)"

  Shim:
    type: Pimoroni Motor SHIM
    subtype: DRV8833
    pinlabels:
      - M1+            # 1
      - M1-            # 2
      - M2+            # 3
      - M2-            # 4
      - VSYS (In)      # 5
      - GND (In)       # 6
    notes: "PIM617 - Soldered onto Pico (Shares VSYS/GND)"

  Pi:
    type: Raspberry Pi Zero 2 W
    pinlabels: [5V In, GND, TX GPIO14, RX GPIO15]
    notes: "CE08211 - Cognition (Linux, WiFi, Camera)"

  IMU:
    type: Adafruit BNO055
    subtype: STEMMA QT 9-DOF
    pinlabels: [VIN 3V3, GND, SDA, SCL]
    notes: "ADA4646 - Orientation Sensor"

  LM:
    type: Pololu 50:1 HP 6V
    subtype: w/ 12 CPR Encoder
    pinlabels: [Motor +, Motor -, Enc VCC, Enc GND, Enc A, Enc B]
    notes: "POLOLU-5161"

  RM:
    type: Pololu 50:1 HP 6V
    subtype: w/ 12 CPR Encoder
    pinlabels: [Motor +, Motor -, Enc VCC, Enc GND, Enc A, Enc B]
    notes: "POLOLU-5161"

cables:
  # --- POWER INPUT & REGULATION ---
  CABLE - Batt to PB:
    colors: [RD, BK]
    category: bundle
    show_name: false
    show_wirecount: false

  CABLE - PB to Reg:
    colors: [RD, BK]
    category: bundle
    show_name: false
    show_wirecount: false

  CABLE - Reg 5V Out:
    colors: [OG]
    category: bundle
    show_name: false
    show_wirecount: false

  # --- POWER DISTRIBUTION ---
  CABLE - Power to P:
    colors: [OG, BK]
    category: bundle
    show_name: false
    show_wirecount: false

  CABLE - Power to Pi:
    colors: [OG, BK]
    category: bundle
    show_name: false
    show_wirecount: false

  CABLE - 3V3 from P:
    colors: [RD]
    category: bundle
    show_name: false
    show_wirecount: false

  CABLE - IMU Power:
    colors: [BU, BK]
    category: bundle
    show_name: false
    show_wirecount: false

  CABLE - Shim Internal Power:
    colors: [OG, BK]
    category: bundle
    show_name: false
    show_wirecount: false

  # --- UART (direct, point-to-point) ---
  CABLE - UART Direct:
    # Removed redundant GND (BK)
    colors: [YE, OG]
    category: bundle
    show_name: false
    show_wirecount: false

  # --- I2C (via protoboard for pull-ups) ---
  CABLE - I2C P to PB:
    colors: [GN, GN]
    category: bundle
    show_name: false
    show_wirecount: false

  CABLE - I2C PB to IMU:
    colors: [GN, GN]
    category: bundle
    show_name: false
    show_wirecount: false

  # --- ENCODER SIGNALS (via protoboard) ---
  CABLE - Left Enc Sig:
    colors: [YE, WH]
    category: bundle
    show_name: false
    show_wirecount: false

  CABLE - Right Enc Sig:
    colors: [YE, WH]
    category: bundle
    show_name: false
    show_wirecount: false

  # --- MOTORS (direct from SHIM) ---
  CABLE - LM Drive:
    colors: [RD, BK]
    category: bundle
    show_name: false
    show_wirecount: false

  CABLE - LM Enc Cable:
    colors: [BU, GN, YE, WH]
    category: bundle
    show_name: false
    show_wirecount: false

  CABLE - RM Drive:
    colors: [RD, BK]
    category: bundle
    show_name: false
    show_wirecount: false

  CABLE - RM Enc Cable:
    colors: [BU, GN, YE, WH]
    category: bundle
    show_name: false
    show_wirecount: false
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

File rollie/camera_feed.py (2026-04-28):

import time
import sys
import os
import signal
import numpy as np
from stats import SystemStats
from PIL import Image, ImageDraw, ImageFont

# Import WhisPlay driver
try:
    from WhisPlay import WhisPlayBoard
except ImportError:
    print("Error: WhisPlay.py not found. Please ensure it is in the same directory.")
    sys.exit(1)

# Import Picamera2
try:
    from picamera2 import Picamera2, H264Encoder
except ImportError:
    try:
        from picamera2 import Picamera2
        # Fallback/Older version checking if needed, but H264Encoder is standard
        # If it fails, maybe 'encoders' module?
        from picamera2.encoders import H264Encoder
    except ImportError:
        print("Warning: H264Encoder not directly found. Assuming Picamera2.H264Encoder exists or handled.")
        from picamera2 import Picamera2
        # Mock or rely on main scope if it was attached
        
except Exception as e:
    print(f"Error importing picamera2: {e}")
    sys.exit(1)

# Configuration
WIDTH = 240
HEIGHT = 280
FPS = 50

# User configuration — copy rollie/config.py.example to rollie/config.py and fill in your values
try:
    from config import USER_IP, USER_NAME, USER_PASS, DEST_DIR
except ImportError:
    print("Error: config.py not found. Copy config.py.example to config.py and fill in your values.")
    sys.exit(1)

def signal_handler(sig, frame):
    print("\nExiting...")
    raise KeyboardInterrupt

signal.signal(signal.SIGINT, signal_handler)

# Helper for large fonts
def get_font(size):
    try:
        return ImageFont.truetype("/usr/share/fonts/truetype/dejavu/DejaVuSans-Bold.ttf", size)
    except:
        return ImageFont.load_default()

def draw_lightning(draw, x, y, size, color):
    # Simple lightning bolt polygon
    # Points relative to x,y center-ish
    points = [
        (x + 2, y), 
        (x - 3, y + size//2), 
        (x - 1, y + size//2), 
        (x - 4, y + size), 
        (x + 1, y + size//2), 
        (x + 4, y + size//2)
    ]
    draw.polygon(points, fill=color)

def draw_globe(draw, x, y, size, color):
    # Circle
    draw.ellipse([x, y, x+size, y+size], outline=color, width=1)
    # Equator
    draw.line([x, y+size//2, x+size, y+size//2], fill=color, width=1)
    # Meridian
    draw.arc([x+size//4, y, x+size*0.75, y+size], 0, 360, fill=color, width=1)

def draw_thermo(draw, x, y, size, color):
    # Bulb
    bx = x + size//2
    draw.ellipse([bx-3, y+size-6, bx+3, y+size], fill=color)
    # Stem
    draw.line([bx, y, bx, y+size-3], fill=color, width=2)
    
import socket
import threading
import subprocess
import shutil
from datetime import datetime
import serial

# Serial Configuration for Pico
SERIAL_PORT = "/dev/serial0"
SERIAL_BAUD = 9600
pico_serial = None
try:
    pico_serial = serial.Serial(SERIAL_PORT, SERIAL_BAUD, timeout=0)
    print(f"Opened Serial Port: {SERIAL_PORT}")
except Exception as e:
    print(f"Warning: Could not open {SERIAL_PORT} - {e}")

# YUV420 to RGB Conversion Helper
def yuv420_to_rgb(yuv_data, width, height):
    # YUV420 (I420/NV12/NV21) comes as 1.5x height
    # We assume I420 (Planar: Y full, U quarter, V quarter) or NV12 from Picamera2 default
    # Picamera2 capture_array usually returns valid buffer structure but might be planar concatenation
    # Actually, for Picamera2, capture_array with "format='YUV420'" returns I420 usually.
    
    # Extract Y
    y = yuv_data[:height, :width]
    
    # Extract UV
    # I420: Y (w*h) + U (w/2 * h/2) + V (w/2 * h/2)
    # But often U and V are flattened or structured. 
    # Let's handle generic conversion assuming standard memory layout.
    
    # Fast path: try to use OpenCV if it existed, but it doesn't.
    # Manual NumPy with slicing to handle strided buffers (padding):
    # DIAGNOSIS V2: User reported yellow line at right edge.
    # Implies previous "Packed Side-by-Side" (0..240, 240..480) was close but mismatched.
    # Hardware likely aligns planes to 32 bytes (256 bytes for 512 stride).
    # Stride = 512. Width/2 = 240.
    # U: 0..240. (Padding 240..256).
    # V: 256..496. (Padding 496..512).
    
    stride = yuv_data.shape[1]
    
    # 1. Extract Y Plane (using slice to ignore stride padding)
    Y = yuv_data[:height, :width].astype(np.float32)
    
    # 2. Extract UV Planes (Planar I420: U then V)
    uv_h = height // 2
    uv_w = width // 2
    
    # Slice UV rows
    UV_view = yuv_data[height:, :]
    
    # Flatten to treat as sequential blocks
    UV_flat = UV_view.flatten()
    
    # Split into U and V (equal size)
    # Total UV bytes = stride * uv_h
    # U bytes = (stride * uv_h) / 2
    # V bytes = (stride * uv_h) / 2
    sz = UV_flat.size // 2
    
    U_flat = UV_flat[:sz]
    V_flat = UV_flat[sz:]
    
    # Reshape to (uv_h, stride // 2)
    # Note: Stride in Y is for full width. Chroma stride is usually half Y stride.
    chroma_stride = stride // 2
    
    U_full = U_flat.reshape((uv_h, chroma_stride))
    V_full = V_flat.reshape((uv_h, chroma_stride))
    
    # Crop to valid width
    U_part = U_full[:, :uv_w].astype(np.float32)
    V_part = V_full[:, :uv_w].astype(np.float32)

    # Upsample (Repeat rows x2, Repeat cols x2)
    U = U_part.repeat(2, axis=0).repeat(2, axis=1)
    V = V_part.repeat(2, axis=0).repeat(2, axis=1)
    
    # Adjust for center
    U -= 128
    V -= 128
    
    # Standard BT.601 conversion
    R = Y + 1.402 * V
    G = Y - 0.344136 * U - 0.714136 * V
    B = Y + 1.772 * U
    
    # Clip and cast
    R = np.clip(R, 0, 255).astype(np.uint8)
    G = np.clip(G, 0, 255).astype(np.uint8)
    B = np.clip(B, 0, 255).astype(np.uint8)
    
    # Stack
    rgb = np.dstack((R, G, B))
    return rgb

# ... existing imports ...

# Global State
is_paused = False
is_recording = False
demo_mode_active = False
recording_process = None
recording_filename_base = None
pending_action = None # 'record', 'demo_toggle'

# Thread-safe trigger
def trigger_action(action):
    global pending_action
    pending_action = action

# Button Logic
press_start_time = 0

def handle_whisplay_press():
    global press_start_time
    press_start_time = time.time()
    # print("Button Pressed")

def handle_whisplay_release():
    global press_start_time
    duration = time.time() - press_start_time
    # print(f"Button Released (Duration: {duration:.2f}s)")
    
    if duration > 0.5: # Long Press (> 0.5s) -> DEMO TOGGLE
        trigger_action('demo_toggle')
    else: # Short Press -> RECORD
        trigger_action('record')
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

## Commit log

2025-12-25 camera working
2025-12-28 after fixing video freeze by resetting the camera
    [camera_feed.py, stats.py]
2026-03-08 motors working via uart0
2026-03-08 Restore motor control by adding missing firmware files
    - Added bno055_minimal.py: a placeholder driver to prevent ImportError when IMU is missing.
    - Added deploy_to_pico.py: a script to flash Pico firmware via USB cereal REPL from Pi Zero.
    - Updated upgrade_pico.sh: switched from Wi-Fi to USB flashing using deploy_to_pico.py.
    - Staged keyboard_control.py which was previously untracked.
    These files ensure the Pico can boot and listen for UART commands on UART0 for motor control.
    [bno055_minimal.py, deploy_to_pico.py, keyboard_control.py]
2026-03-08 Add flash_pico flag to automate factory deployment
    Allows syncing UF2 files and automatically mounting/flashing
    MicroPython with an interactive 5-second opt-in promptly,
    then auto-deploys Python scripts to the Pico when it boots.
2026-03-08 Repurpose Whisplay long-press to motor demo mode
    - The long press (>0.5s) on the Whisplay screen now toggles sending and over to the Pico.
    - Removed the pause screen logic.
    - Maintains WASD functionality as keyboard control input.
2026-03-08 Auto-detect missing Pico for factory flash prompt
2026-03-09 Reduce motor demonstration and WASD speeds by 10x
2026-03-16 Fix motor speed mapping with min_duty offset and add timing-based friction kick. Add --hide-telemetry option to keyboard_control.py
    [Slewing Bearing v1.scad, cradle.scad, cradle.stl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]
2026-04-24 Prepare project for public release as v0.1
    - Add README with project narrative, hardware BOM, build guide, usage, and image placeholders
    - Add MIT LICENSE
    - Remove hardcoded credentials from camera_feed.py and sync_and_run_on_py.sh; replace with config.py / sync_config.sh pattern (example files provided, actuals gitignored)
    - Add stub comment to bno055_minimal.py documenting Direct Drive fallback behaviour
    - Move debug/test scripts (debug_battery.py, simulate_logic.py, test_camera_config.py) to tools/
    - Archive intermediate CAD iterations to cad/archive/; keep only final STLs and all SCAD sources in cad/
    - Delete cad/single_part.stl (unidentified, unused)
    - Add images/ directory with placeho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
    [cradle.stl, cradle_v1.stl, single_part.stl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]
2026-04-24 docs: update README with motivation section and fix bearing terminology
    - Replace "lazy susan" with the correct term "slewing bearing" throughout
    - Add Motivation section drawing from the original presentation slides
    - Export ballie_slides.txt content to ballie_slides.md
2026-04-24 tidying up presentation material
2026-04-28 docs: add real build photos and rework README image layout
    Replace zero-byte placeholder images with actual build photos (early
    WIP, stator subassemblies, CAD/wiring screenshots, finished ball, and
    a rolling clip), rename to descriptive filenames, and standardise
    image sizing in the README — portraits constrained to a single width
    with clustered side-by-side groupings, landscapes left at natural
    size.
2026-04-28 docs: drop Samsung Ballie inline image, size assembly photos to 320
    The Samsung concept reference is now just a link in the Motivation
    section. The Assembly and Wiring section's four photos are now all
    constrained to width 320 for consistency.
2026-04-28 docs: drop wiring_diagram_detail image from Assembly section
2026-04-28 docs: add second hero photo (camera + IMU through gap) side-by-side
2026-04-28 docs: place hero pair below description, hero shot first, equal height
    Hero photos no longer float; they sit on their own line below the
    lead description. Both use height=320 so they match in height
    regardless of aspect ratio, with a small gap between them. Order:
    screen shot first, camera+IMU shot second.
2026-04-28 docs: tighten Motivation paragraph and refresh hero image
2026-04-28 docs: remove Assembly and Wiring photos from README
2026-04-28 docs: shrink Current State triptych to width=240, force single-row layout
2026-04-28 docs: add cad_wheel screenshot and BOM bullet to AI Co-Engineer section
    Mechanical design now shows three CAD screenshots (slewing bearing,
    stator ring, motor wheel hub). Adds a 'Bill of materials' bullet
    calling out that the parts list itself was researched with AI help.
    Removes the duplicate wheel render from the 3D Printing section.
2026-04-28 refactor: rename project from Ballie to Rollie
    Renames the project name everywhere it referred to itself: README,
    docs, scripts, firmware, CAD headers, wiring YAML titles, gitignore
    entries, service name, runtime artefact paths, and the source
    package directory (ballie/ -> rollie/).
    The single remaining "Ballie" mention in README.md is preserved on
    purpose: it refers to Samsung's concept robot, which inspired this
    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
    [Slewing Bearing v1.scad, slewing_bearing.scad, slewing_bearing_flexible.scad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]
